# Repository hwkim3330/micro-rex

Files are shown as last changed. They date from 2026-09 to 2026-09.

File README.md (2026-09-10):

# MICRODUCK 원본으로 복귀

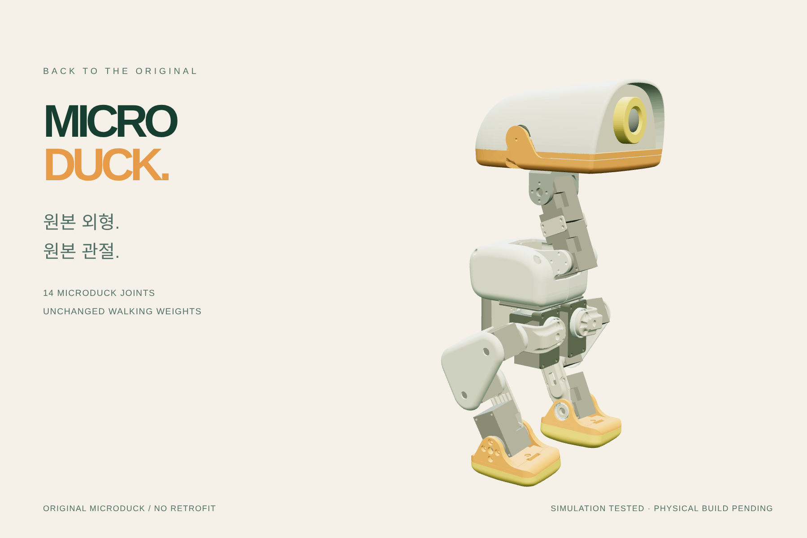
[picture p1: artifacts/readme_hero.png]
Microduck 원본 모델


현재 기본 화면은 **공룡 외장을 제거한 Microduck 원본**입니다. 원본 14개 관절과 공식 가중치의 계산 기록을 유지합니다. 이전 Micro Rex 외장은 비교 메뉴와 설계 기록으로 보존합니다.

원본 하드웨어의 비상업 조건은 그대로이며, 별도 상업용 독자 설계 [Micro X](https://github.com/hwkim3330/micro-x)의 권리 범위와 혼동하지 않습니다.

[원본 3D 보기](https://hwkim3330.github.io/micro-rex/web/) · [원본 외형 GLB](models/microduck_original.glb) · [원본 모델·자산](vendor/microduck/)

## 이전 Micro Rex 외장 기록

큰 눈, 작은 앞발, 긴 꼬리. **Microduck의 14개 관절과 공식 보행 가중치를 유지하는 작은 티렉스**를 만듭니다. 이 절은 이전 외장 설계 기록입니다.

[3D 모델 돌려보기](https://hwkim3330.github.io/micro-rex/) · [도면 PDF](drawings/Micro_Rex_Drawings.pdf) · [STEP 조립 파일](models/micro_rex_retrofit.step) · [GLB 전체 모델](models/micro_rex.glb) · [출력 STL](models/print/) · [검증 보고서](artifacts/validation.json)

현재 모델은 **Rev C 호환 외장 프로토타입**입니다. 눈의 뒤쪽 나사 고정, 머리 스트랩 슬롯, 안쪽 경량 포켓과 가장자리 보강부를 추가했습니다. 공식 가중치의 시뮬레이션, 무게중심 및 눈 고정부의 디지털 검사를 제공합니다. 실물 강도와 보행 시험은 아직 남아 있습니다.

먼저 **같은 관절의 Micro Rex**를 검증하고, 그다음 **저가형 Nano Rex**를 개발합니다. 네발형은 공개 모델에서 내렸습니다. [제품 순서와 완료 기준](docs/PRODUCT_SEQUENCE.md)

[가중치 시험](docs/POLICY_COMPATIBILITY.md) · [무게중심](artifacts/balance_study.json) · [눈 고정부](artifacts/retention_check.json)

## 무엇을 만들었나

- 카메라 앞을 개방한 둥근 볼판, 뒤쪽에서 나사로 고정하는 큰 눈, 위쪽 스트랩 브리지.
- 작은 앞발과 장착 브래킷, 속이 빈 분할 꼬리와 스트랩 장착판.
- 수정 가능한 CadQuery 원본, 개별 STEP/STL, 16개 부품의 출력 방향 정리본.
- 전체 로봇 GLB, 외장 STEP 조립 파일, MuJoCo 모델 및 지면이 포함된 장면.
- 실제 형상에서 생성한 17쪽 치수 참고 도면과 부품 목록.
- PC·모바일 브라우저에서 회전·확대·분해 보기 및 원본 부품 표시 전환.

기존 Microduck보다 개선하려는 항목은 외장 수정/교체의 용이성, 출력 파일·도면 제공, 추적 가능한 호환성 검사입니다. 속도·안정성·배터리 수명 향상은 아직 입증하지 않았습니다.

## 호환성 확인 범위

| 항목 | 결과 |
|---|---|
| 원본 정책 제어 관절 | **14개**, 이름·순서 유지 |
| 관절 축·위치·가동 범위 | 원본과 배열 비교 통과 |
| 액추에이터 연결·제어 범위·힘 제한 | 원본과 배열 비교 통과 |
| 센서 종류·차원·연결 ID | 원본과 배열 비교 통과 |
| 원본 모델 질량 | 737.24 g |
| Micro Rex 모델 질량 | 783.77 g, 추가 체결구 실측 전 |
| 예상 외장 추가 질량 | 46.53 g, PLA 실체적 환산 |
| 새 출력 STL | 16개, 폐곡면 및 양의 체적 검사 통과 |
| 단순 PD 자세 유지 | **원본과 Micro Rex 모두 3초 직립 실패**; 정책 평가가 아님 |
| 공식 ONNX + BAM 평지 시험 | 원본 12회 + 외장 12회, 각 10초 넘어짐 기준 미도달; 속도·방향 추종 부족 |
| 공식 서기 가중치 + 머리 명령 | 원본 3회 + 외장 3회, 각 10초 넘어짐 기준 미도달 |
| 같은 HOME 자세의 무게중심 변화 | 뒤로 0.96 mm / 위로 4.58 mm; 두 발 접지 가정의 정적 계산 |
| 눈·와셔 체결 공간 | 6개 STEP 조합 겹침 없음; 인발·토크 실물 시험 전 |
| 실물 조립 / sim-to-real | **미검증** |

원본 로봇의 입 모터는 14차원 보행 정책과 별도입니다. 이 패키지는 입 모터 제어를 추가하거나 15차원 정책으로 바꾸지 않습니다. 꼬리·앞발은 정적 외장입니다. 추가 질량과 관성은 모델에 반영했으며, 기존 보행 정책을 그대로 쓰면 동일 성능이 나온다고 보장하지 않습니다.

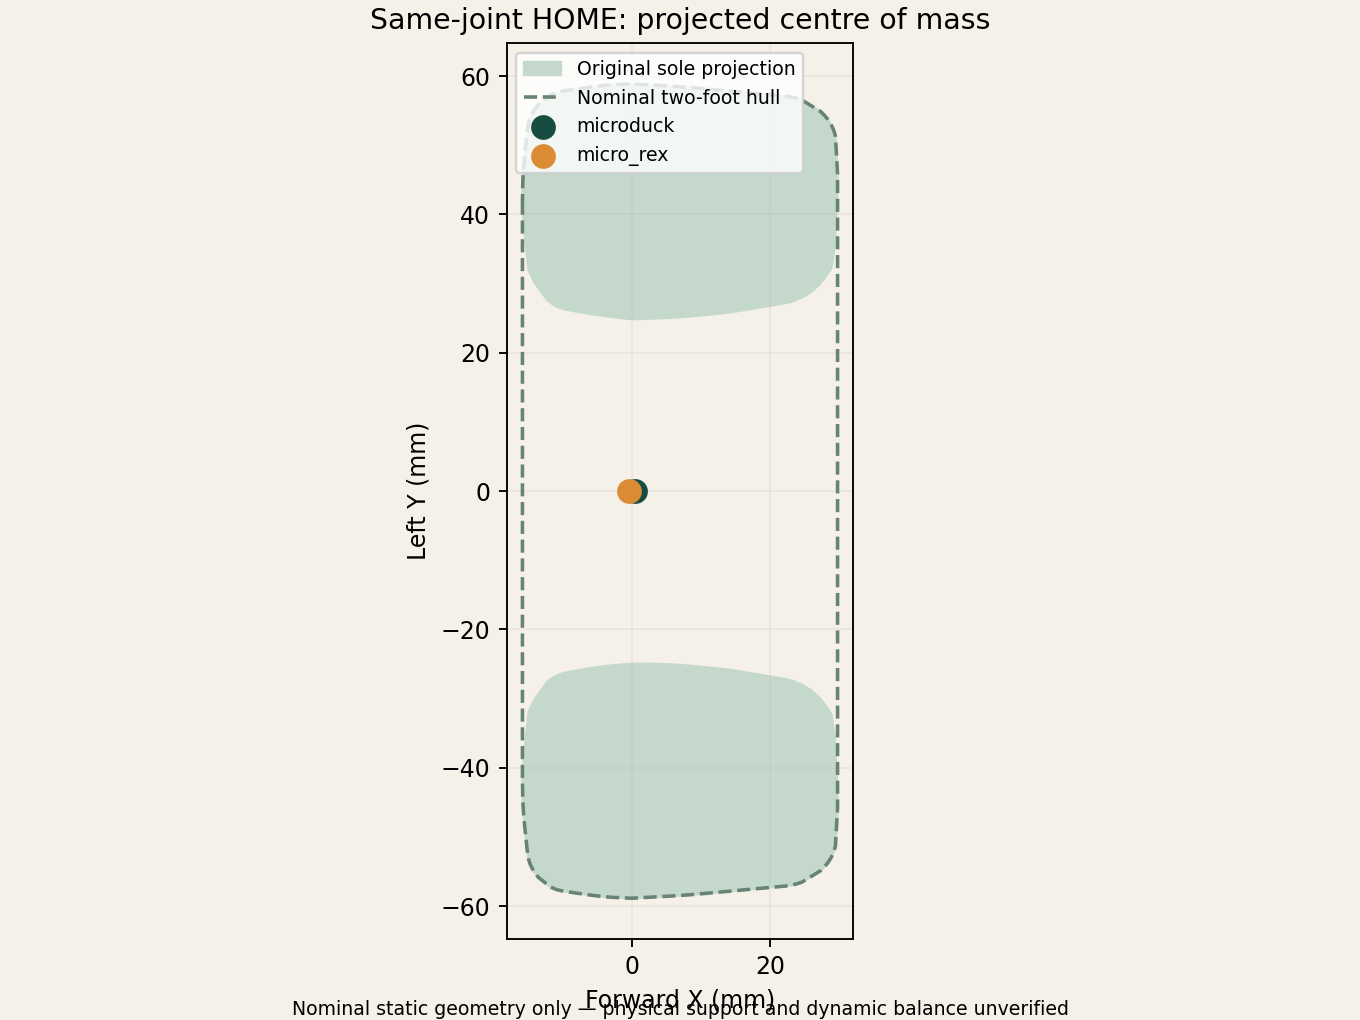
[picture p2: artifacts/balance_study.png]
원본과 Micro Rex의 정적 무게중심 투영 비교


목·머리 각도를 바꾼 일곱 자세에서 가정한 두 발 지지영역까지 최소 여유는 7.46 mm입니다. 실제 접촉력이나 보행 중 안정성을 증명하는 값은 아닙니다. 머리 5g·몸통 5g의 미실측 체결구 예산도 별도 민감도 계산에 기록했습니다.

## 원본 자료도 함께 받기

공식 제어 소프트웨어, 공식 RL/메시, 공식 Robot HAT 회로도, 커뮤니티 역설계 도면을 서로 구분해 고정 커밋으로 연결합니다.

```bash
git clone --recurse-submodules https://github.com/hwkim3330/micro-rex.git
cd micro-rex
```

이미 클론했다면 `git submodule update --init --recursive`를 실행합니다. 모든 출처와 커밋은 [upstream.lock.json](upstream.lock.json), 자료별 상태는 [출처 기록](docs/SOURCES.md)에 있습니다. 커뮤니티 역설계 자료는 공식 공장 도면으로 취급하지 않습니다.

## 모델 재생성

Python 3.11 이상, Linux 기준입니다.

```bash
python -m venv .venv
source .venv/bin/activate
pip install -r requirements.txt
python cad/build.py
python tools/print_parts.py
python tools/tail_continuous.py
python tools/retention_check.py
python tools/balance_study.py
python tools/validate.py
MUJOCO_GL=egl python tools/render.py  # EGL 환경 필요; 정적 렌더는 이미 포함
python tools/drawings.py
```

기구를 변경한 뒤에는 [정책 평가](docs/POLICY_COMPATIBILITY.md)를 다시 실행해야 기존 평가 기록의 모델 SHA가 맞습니다. README 대표 이미지는 `node tools/readme-portrait.mjs`로 현재 GLB와 기록 자세에서 다시 생성합니다.

`models/parts/`는 조립 기준 좌표, `models/print/`는 중심 정렬 및 출력면을 맞춘 파일입니다. 원본 로봇의 STL은 `vendor/microduck/assets/`에 있습니다. 전체 조립 STEP은 **새 외장**만 정확한 CAD 솔리드로 담고, 원본 전체 로봇 형상은 GLB와 upstream STL/MJCF로 제공합니다.

```bash
python -m http.server 5190
# http://127.0.0.1:5190/web/
```

뷰어 라이브러리도 저장소 안에 있으므로 외부 CDN이 필요 없습니다. 모델을 MuJoCo에서 열려면 `models/scene.xml`을 사용합니다.

개발자 브라우저 검사: `npm ci --ignore-scripts && npm run test:viewer`. 설치된 Chrome 경로는 `CHROME_PATH`로 지정할 수 있습니다.

## 제작 전 확인

[조립 및 검증 항목](docs/ASSEMBLY.md)을 먼저 확인하세요. 현재 꼬리 조인트, 스트랩 고정, 나사 체결 길이와 가동 중 간섭은 실물 확인 대상입니다. 도면은 프로토타입 치수 참고용이며 공장 제작 승인도면이 아닙니다.

## 라이선스

독립 프로젝트이며 Pollen Robotics 또는 Hugging Face의 공식 제품이 아닙니다.

- 새 코드: Apache-2.0.
- 원본 하드웨어 모델: upstream의 **CC BY-SA-NC** 표기 유지.
- 새 외장 및 파생 모델·도면: **CC BY-NC-SA 4.0**, 원본 하드웨어 조건도 적용.
- Three.js: MIT.

[자세한 출처·라이선스](licenses/HARDWARE.md). 상업 사용을 허용하는 하드웨어 패키지가 아닙니다.

### 공개 웹 제작실

[GitHub Pages](https://hwkim3330.github.io/micro-rex/)에서 14개 관절 자세 조절, 부품 선택 및 치수 확인, 조립·분해 보기, 원본 부품 표시 전환, 카메라 방향 선택과 PNG 저장을 제공합니다. 부품 표에서 출력용 mm STL과 STEP을 내려받을 수 있습니다. PC와 모바일 레이아웃을 제공합니다.

브라우저 수동 관절 조절은 원본 MJCF에서 생성한 **기구학 시연**입니다. 새로 추가한 **시뮬레이션 기록 재생**은 공식 ONNX 가중치로 계산한 원본·외장 모델의 몸체와 관절 좌표를 재생합니다. 실물 제작과 보행 검증 완료를 의미하지 않습니다.

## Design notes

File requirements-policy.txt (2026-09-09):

# Separate policy environment; CAD generation uses requirements.txt / MuJoCo 3.4.
mujoco==3.10.0
numpy>=2,<3
onnxruntime==1.24.1
better-actuator-models @ git+https://github.com/Rhoban/bam.git@62bd8ce12154340be97e06f7f41a0ca8f116d967

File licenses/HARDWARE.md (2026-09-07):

# Hardware, geometry and attribution

Original Microduck model and meshes: **Pollen Robotics**.
Source: https://github.com/pollen-robotics/microduck_rl
The exact source commit is recorded in `upstream.lock.json`.

The upstream README states: “Hardware design files are licensed under Creative Commons BY-SA-NC.”
It does not specify a version in that notice. The unmodified model files and STL meshes in
`vendor/microduck/` retain those upstream terms; this repository does not relicense them as Apache.
`vendor/microduck/UPSTREAM_README.md` preserves the original notice.

New Micro Rex CAD geometry, derivative assembly meshes, model XML, drawings and renderings:
Copyright 2026 hwkim3330, **CC BY-NC-SA 4.0**, subject also to the original upstream hardware terms.
Attribution: “Micro Rex by hwkim3330, based on Microduck by Pollen Robotics.”
Changes: T-rex cheek shells, decorative teeth/brows, bridges, forelimbs, brackets and tail;
additive inertial properties; assembled reference models and derived drawings.
Non-commercial use only; preserve attribution and ShareAlike when redistributing derivatives.

New build/validation/viewer software is Apache-2.0, except Three.js vendored files,
which retain their included MIT license in `web/vendor/three/LICENSE`.

The community `microduck-replica` and official electronics repositories are linked/pinned as
upstream submodules; their respective licenses remain authoritative. Community reconstructions
are not factory drawings, and are not described as physically verified Micro Rex hardware.

License text for new Micro Rex design work:
https://creativecommons.org/licenses/by-nc-sa/4.0/legalcode.en

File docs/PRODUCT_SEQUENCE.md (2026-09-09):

# Micro Rex first, Nano Rex next

## 1. Micro Rex — same joints

Keep Microduck's 14 policy joints, XL330 actuator class, joint geometry, sensors and 61→14 policy interface. Improve the dinosaur shell, retention, maintenance and presentation. Re-run the unchanged official checkpoint whenever added geometry changes mass, inertia or contacts.

Current Rev C changes: continuous rounded cheeks, larger visible eye whites, M2 rear eye retention, strap slots in both head bridges, rounded forearm corners, and a README portrait rendered from the actual CAD.

Physical acceptance remains open: eye pull/torque tests, shell retention under vibration, cable and camera clearances, repeated head/joint motion, tail mounting, drop testing, thermal tests and actual gait trials. Do not describe an untested shell as tougher than Microduck. Start with coupons and one assembled head before ordering a batch.

## 2. Nano Rex — lower cost

Deferred until the same-joint Micro Rex is validated. Compare actuator, battery, electronics and assembly costs using supplier quotations and loaded-joint measurements. Price and BOM are not fixed yet.

Changing actuator torque, link lengths, joint count or mass distribution invalidates any assumption that the Microduck checkpoint will transfer unchanged. Nano Rex must have its own transfer evaluation and may require retraining. No Nano Rex manufacturing files or claimed price are released yet.

Q4 is retired from the public Micro X viewer; its previous CAD is retained as historical work.

The source hardware's noncommercial terms remain separate from the Apache-2.0 policy weights. Commercial hardware rights need to be resolved before selling a derivative robot.

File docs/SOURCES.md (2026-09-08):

# Sources and scope

Four public repositories were cloned for this work. Exact commits are pinned in `upstream.lock.json` and `.gitmodules` / gitlinks.

| Source | Role | What is and is not established |
|---|---|---|
| [pollen-robotics/microduck](https://github.com/pollen-robotics/microduck) | Official Rust control runtime | Runtime source, configuration and control contract; not a Micro Rex firmware validation |
| [pollen-robotics/microduck_rl](https://github.com/pollen-robotics/microduck_rl) | Official training source, MJCF and STL | Actual reference model used here. `robot_walk.xml` has 14 policy actuators; the runtime's mouth channel is separate |
| [pollen-robotics/elec_RPI_Robot_HAT](https://github.com/pollen-robotics/elec_RPI_Robot_HAT) | Official KiCad electronics | Includes schematic, PCB, production outputs and BOM. Presence of this board does not establish a complete factory robot build package |
| [fanhao375/microduck-replica](https://github.com/fanhao375/microduck-replica) | Community reconstruction | Assembly drawings, inferred mechanical/electronic details; treated as third-party reconstruction, not authoritative factory drawings |

The upstream MJCF links an Onshape document. We preserve the link inside the original XML but do not claim to have retrieved editable original Onshape parts.

The new CAD generator, drawings, build files and viewer are original work in this repository. The complete robot render/GLB and MuJoCo derivative use the official Microduck meshes and preserve their attribution and hardware licensing. No community CAD is silently represented as an original manufacturer file.

`vendor/microduck/` is a ready-to-use snapshot of the official model files and meshes. Full upstream software and hardware repositories are pinned submodules under `upstream/`; retrieve them using `git clone --recurse-submodules`.

The static renders show the reference assembly pose. They are computer-generated views of the delivered model, not photographs of a built Micro Rex.

## Interactive design references

The following user-supplied Spaces were inspected as interaction references. Their application code and additional assets were not copied into this site:

- [Microduck simulator](https://huggingface.co/spaces/pollen-robotics/microduck-simulator), revision `e81974b932c7ca1819843b7bb3dcd42e2993e98e`: simulator presentation and controls.
- [Microduck anatomy](https://huggingface.co/spaces/mishig/microduck-anatomy), revision `5329ff5db7c6baa5c15def88085f842e0221395e`: inspectable anatomy and articulated model interaction.
- [Reachy Mini 3D voice](https://huggingface.co/spaces/pollen-robotics/reachy-mini-3d-voice), revision `bdcac3f73e9b7def1a71ee03d2ca7a858fd0004b`: character and robot presentation.

Our browser rig is independently exported from the vendored upstream MJCF using `tools/export_rig.py`. It preserves body hierarchy, local joint axes, pivots and ranges. It is a kinematic viewer, without collision enforcement, balance control or a voice backend. Moving a slider is not evidence of feasible hardware motion.

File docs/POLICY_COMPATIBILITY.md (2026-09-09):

# Microduck weights compatibility / Rev C

사용자 요청에 따라 Microduck 원본 기구를 유지하는 Micro Rex 호환 개발을 재개했습니다. 판매용 독립 기구 Micro X와 달리, 이 저장소는 원본 하드웨어의 비상업 조건을 유지합니다.

## 실제로 사용한 자료

- 원본 모델과 추론 코드: `upstream.lock.json`의 Microduck RL 커밋. 관절 14개와 관절·몸체 배치, 센서 순서를 유지합니다.
- [공식 정책 저장소](https://huggingface.co/pollen-robotics/microduck-policies/tree/088524a64e2557dc453256b6071dbb9d23888802): `alpha_walking.onnx`를 변경하거나 재학습하지 않았습니다. 다운로드 URL과 SHA256은 `artifacts/policy_source.json`에 고정합니다. 모델 카드의 가중치 라이선스는 Apache-2.0입니다. 이는 하드웨어의 상업 이용 허가가 아닙니다.
- 관측 61개, 행동 14개, 50 Hz. upstream 추론 코드의 HOME 기준 자세, 투영 중력, 관절 상대 위치·속도, 이전 행동과 명령 배열을 사용합니다.
- BAM M6 XL330 모터 모델, 7.4 V, firmware kp 200, 전압 강하 gain 0.1. MuJoCo는 원본 추론 코드가 사용하는 3.10.0을 별도 환경에 설치했습니다. CAD 검사 환경은 3.4.0입니다.

## 비교 결과

평평한 바닥에서 정지, 0.1 m/s 전진, 0.3 m/s 전진, 0.3 rad/s 회전 명령 각각 초기 관절 잡음 seed 3개를 사용해 10초씩 평가했습니다. 원본 12회와 외장 포함 12회에서 정한 넘어짐 기준(몸통 기울기 45° 초과 또는 높이 65 mm 미만)에 도달하지 않았습니다.

외장 모델의 0.3 m/s 명령 시험에서 X 이동은 1.009–1.064 m, Y 이동은 −0.340–−0.202 m였습니다. 속도 및 직진 추종이 명령과 일치하지 않습니다. 0.1 m/s 명령에서는 거의 전진하지 않았고 회전 명령 추종도 작았습니다. 원본에서도 같은 종류의 문제가 나타났습니다. **가중치 로딩·추론·짧은 평지 동작을 확인했지만, 모든 기능의 호환이나 실물 보행을 검증한 것은 아닙니다.**

외장은 46.53 g의 추정 질량과 관성을 더합니다. 추가 나사·와셔·스트랩의 실측 질량은 포함 전입니다. 외장 충돌은 보수적 단순 형상으로 근사하며 실물 간섭이나 강도 검증을 대체하지 않습니다. 상세 수치는 `artifacts/policy_evaluation.json`을 따릅니다.

별도로 공식 `alpha_stand.onnx`를 그대로 사용해 머리 pitch 명령 −0.25/0/+0.25 rad, seed 0으로 두 모델을 각 3회 시험했습니다. 10초 동안 넘어짐 기준에는 도달하지 않았습니다. 이 시험도 명령 추종 정확도나 장기 신뢰성의 합격 판정은 아닙니다.

## 재현

```sh
git submodule update --init upstream/microduck_rl
python3 -m venv .venv-policy
.venv-policy/bin/python -m pip install -r requirements-policy.txt
.venv-policy/bin/python tools/fetch_policy.py
.venv-policy/bin/python tools/evaluate_policy.py
```

가중치는 `.cache/policies`에 저장하며 이 저장소에서 다시 배포하지 않습니다. 다운로드는 고정 리비전을 사용하고 평가 전에 SHA256을 대조합니다. walking 비교 24회와 standing/head 비교 6회를 수행합니다. 가상 환경과 모델 가중치는 git에서 제외합니다.

웹의 기록 재생은 이 평가에서 저장한 실제 관절·몸체 좌표를 사용합니다. ONNX를 브라우저에서 실행하거나 실제 로봇을 연결하는 기능은 아닙니다. 현재 기록은 전진 0.3 m/s, seed 0 시험입니다.

## 외장 변경

원본 머리와 다리 구조를 유지하고 옆 볼을 곡선으로 다듬고 주둥이 길이를 줄였습니다. 기존 `brow_*` 부품 ID는 큰 볼록 눈 부품으로 변경했습니다. 눈동자는 도색 의도이며 MuJoCo의 검은 표시는 시각 근사입니다. 실제 눈 부품 고정, 커버와 원본 하우징 간 공차 및 카메라 시야 확인은 남아 있습니다.

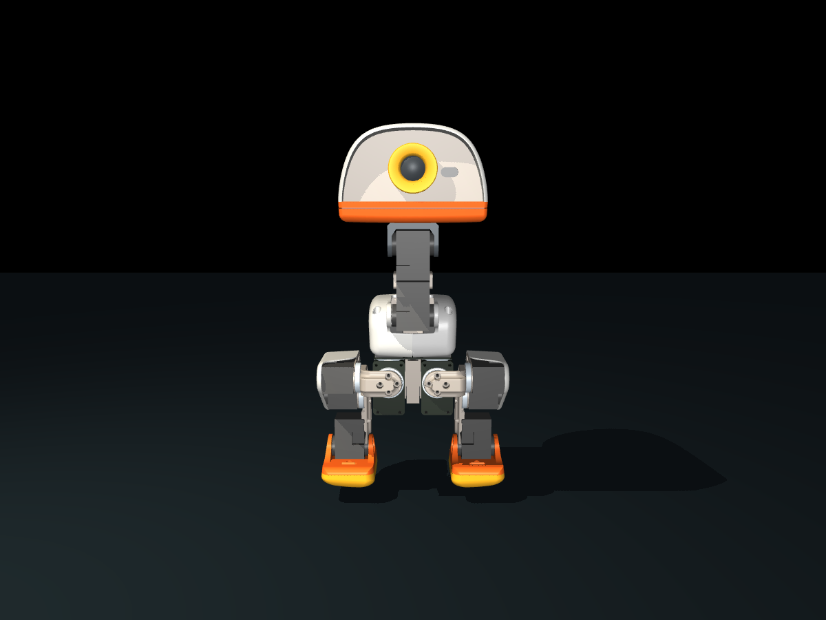
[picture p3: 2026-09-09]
artifacts/microduck_reference_front.png

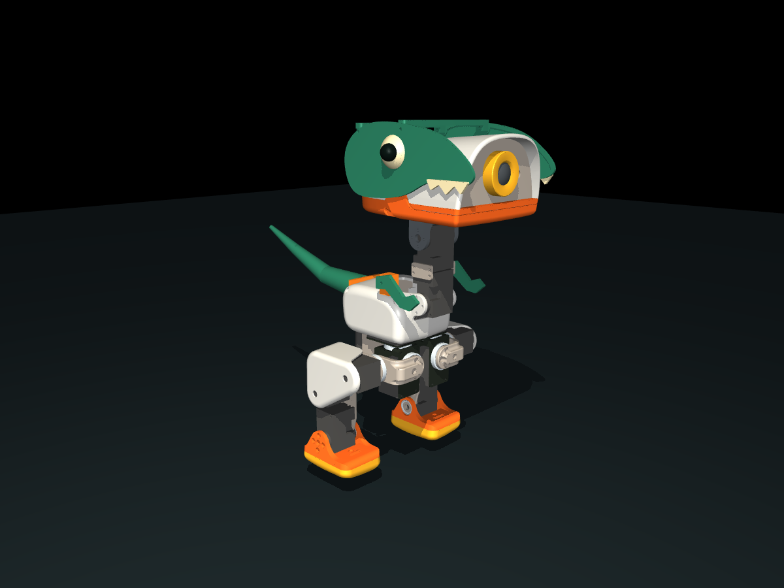
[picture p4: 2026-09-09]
artifacts/micro_rex_hero.png

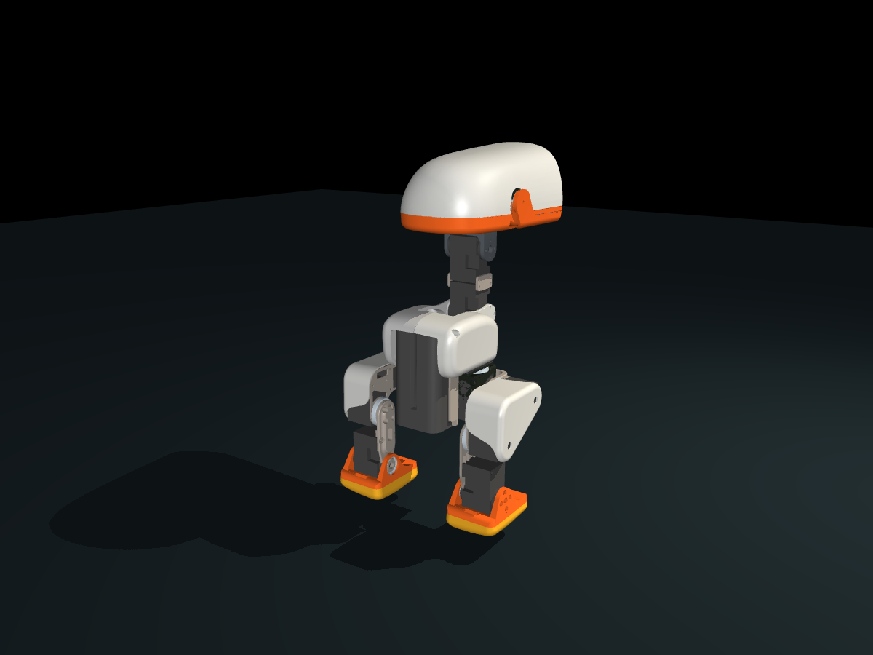
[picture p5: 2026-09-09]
artifacts/microduck_reference_rear.png

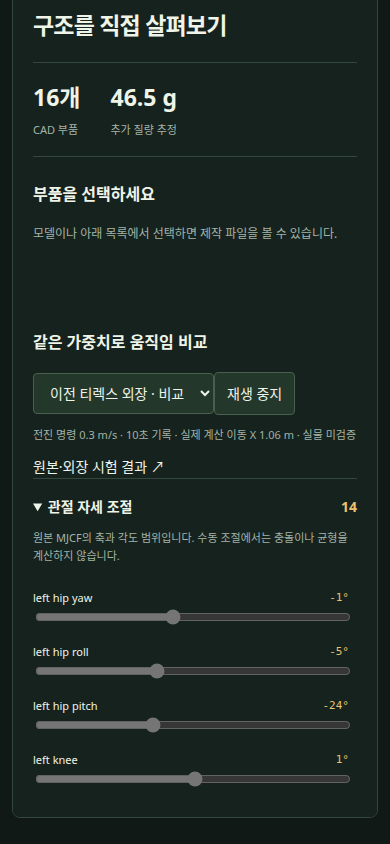
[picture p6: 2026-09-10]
artifacts/policy_mobile.png

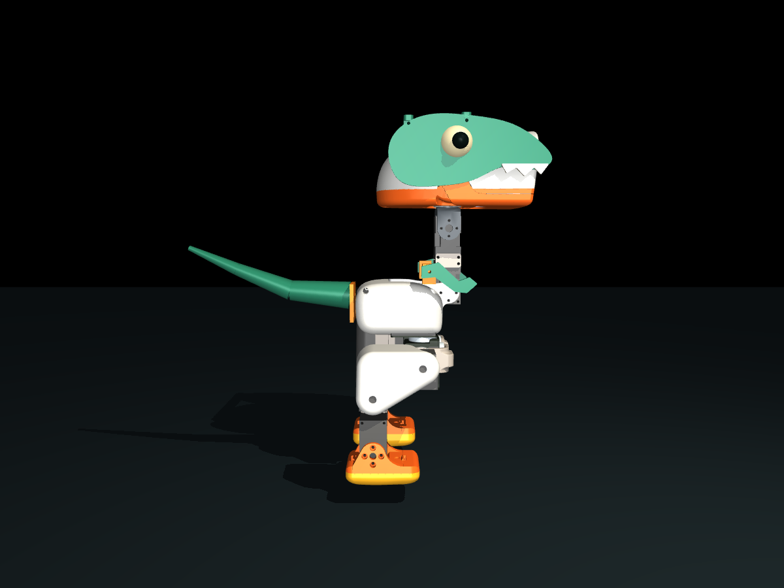
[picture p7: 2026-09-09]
artifacts/micro_rex_side.png

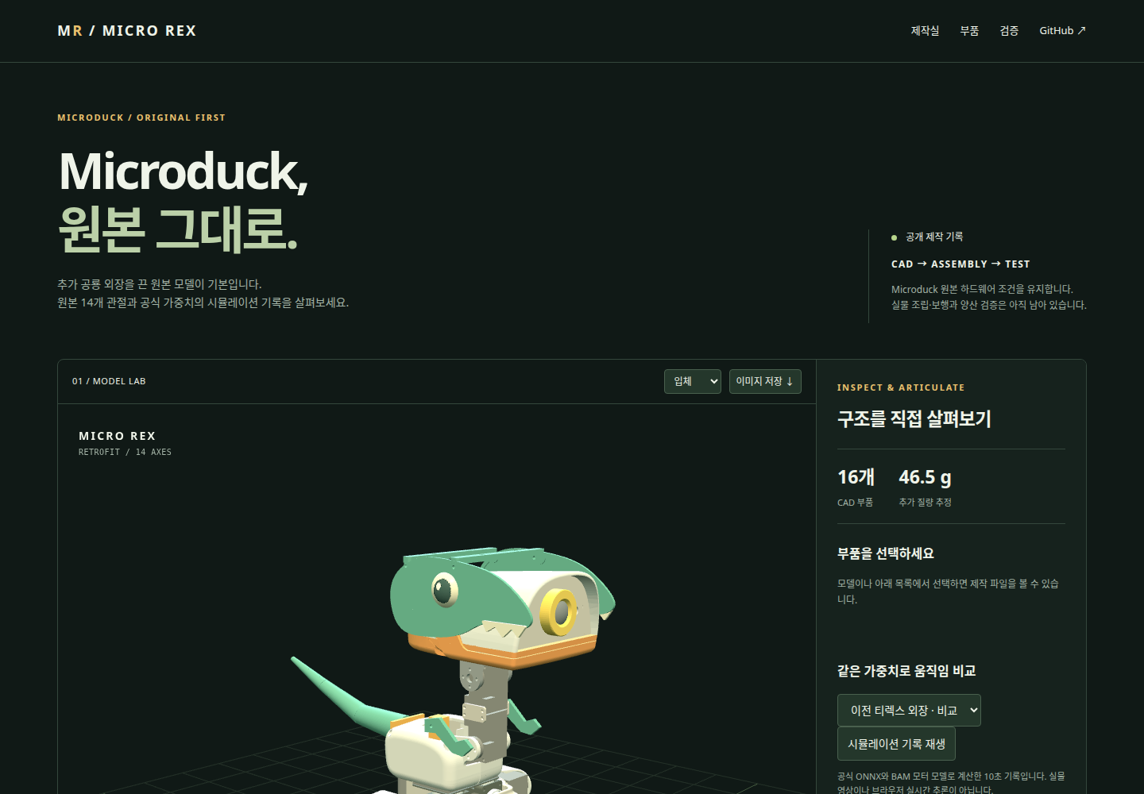
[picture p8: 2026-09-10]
artifacts/viewer_desktop.png

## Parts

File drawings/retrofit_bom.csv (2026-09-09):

part | qty | material_estimate | mass_g | STL | STEP
skull_cheek_left | 1 | PLA estimate, density 1.24 g/cm3 | 7.688 | models/parts/skull_cheek_left.stl | models/step/skull_cheek_left.step
teeth_left | 1 | PLA estimate, density 1.24 g/cm3 | 0.44 | models/parts/teeth_left.stl | models/step/teeth_left.step
brow_left | 1 | PLA estimate, density 1.24 g/cm3 | 1.917 | models/parts/brow_left.stl | models/step/brow_left.step
skull_cheek_right | 1 | PLA estimate, density 1.24 g/cm3 | 7.688 | models/parts/skull_cheek_right.stl | models/step/skull_cheek_right.step
teeth_right | 1 | PLA estimate, density 1.24 g/cm3 | 0.44 | models/parts/teeth_right.stl | models/step/teeth_right.step
brow_right | 1 | PLA estimate, density 1.24 g/cm3 | 1.917 | models/parts/brow_right.stl | models/step/brow_right.step
head_bridge_1 | 1 | PLA estimate, density 1.24 g/cm3 | 3.447 | models/parts/head_bridge_1.stl | models/step/head_bridge_1.step
head_bridge_2 | 1 | PLA estimate, density 1.24 g/cm3 | 3.447 | models/parts/head_bridge_2.stl | models/step/head_bridge_2.step
tail_segment_1 | 1 | PLA estimate, density 1.24 g/cm3 | 5.107 | models/parts/tail_segment_1.stl | models/step/tail_segment_1.step
tail_segment_2 | 1 | PLA estimate, density 1.24 g/cm3 | 3.28 | models/parts/tail_segment_2.stl | models/step/tail_segment_2.step
tail_segment_3 | 1 | PLA estimate, density 1.24 g/cm3 | 1.376 | models/parts/tail_segment_3.stl | models/step/tail_segment_3.step
tail_saddle | 1 | PLA estimate, density 1.24 g/cm3 | 3.415 | models/parts/tail_saddle.stl | models/step/tail_saddle.step
forearm_left | 1 | PLA estimate, density 1.24 g/cm3 | 1.527 | models/parts/forearm_left.stl | models/step/forearm_left.step
arm_standoff_left | 1 | PLA estimate, density 1.24 g/cm3 | 1.655 | models/parts/arm_standoff_left.stl | models/step/arm_standoff_left.step
forearm_right | 1 | PLA estimate, density 1.24 g/cm3 | 1.527 | models/parts/forearm_right.stl | models/step/forearm_right.step
arm_standoff_right | 1 | PLA estimate, density 1.24 g/cm3 | 1.655 | models/parts/arm_standoff_right.stl | models/step/arm_standoff_right.step
eye_retention_screw | 2 | Candidate M2 x 6 plastic thread-forming; supplier/torque pending
eye_retention_washer | 2 | Candidate OD8 ID2.2 thickness0.5 mm; physical fit pending
head_retention_strap | 2 | Candidate for 4 x 2 mm slots; routing/strength pending

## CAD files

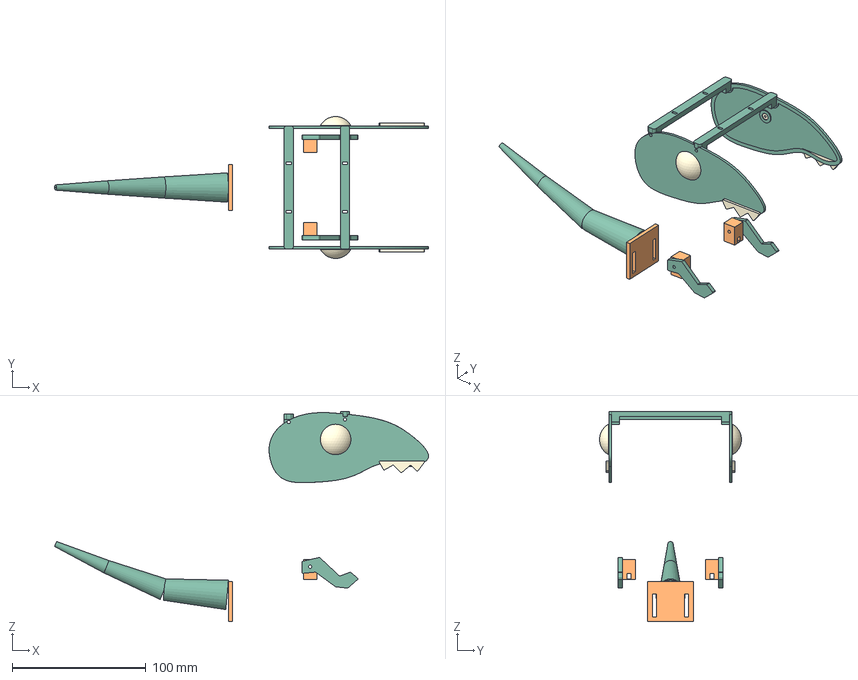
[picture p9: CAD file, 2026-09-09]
models/micro_rex_retrofit.step
279.1 x 105.9 x 157.0 mm
skull_cheek_left
teeth_left
brow_left
skull_cheek_right
teeth_right
brow_right
head_bridge_1
head_bridge_2
tail_segment_1
tail_segment_2
tail_segment_3
tail_saddle
forearm_left
arm_standoff_left
forearm_right
arm_standoff_right

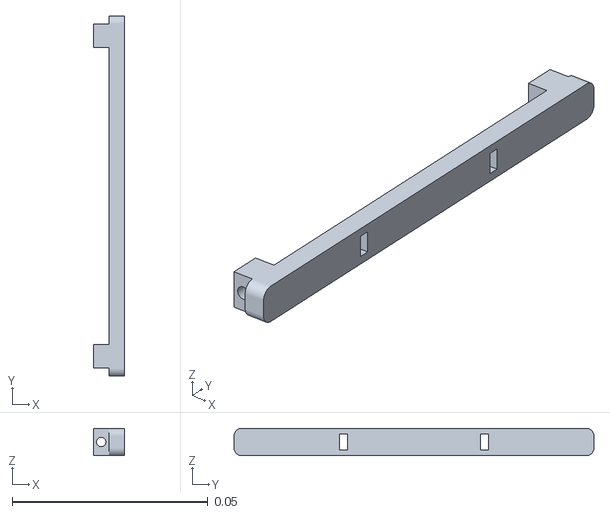
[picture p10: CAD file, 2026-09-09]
models/parts/head_bridge_2_local.stl
0.008 x 0.092 x 0.007

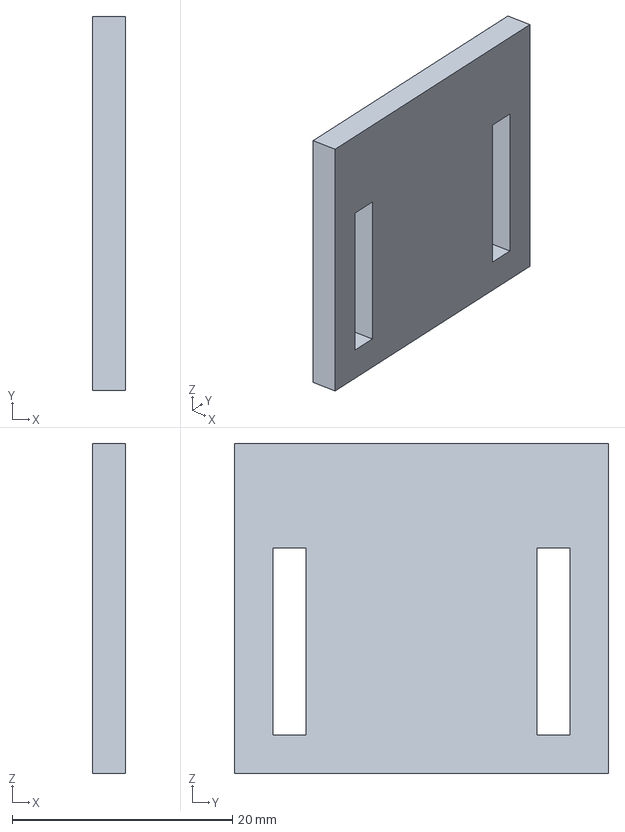
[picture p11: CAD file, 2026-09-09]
models/step/tail_saddle.step
3.00 x 34.0 x 30.0 mm

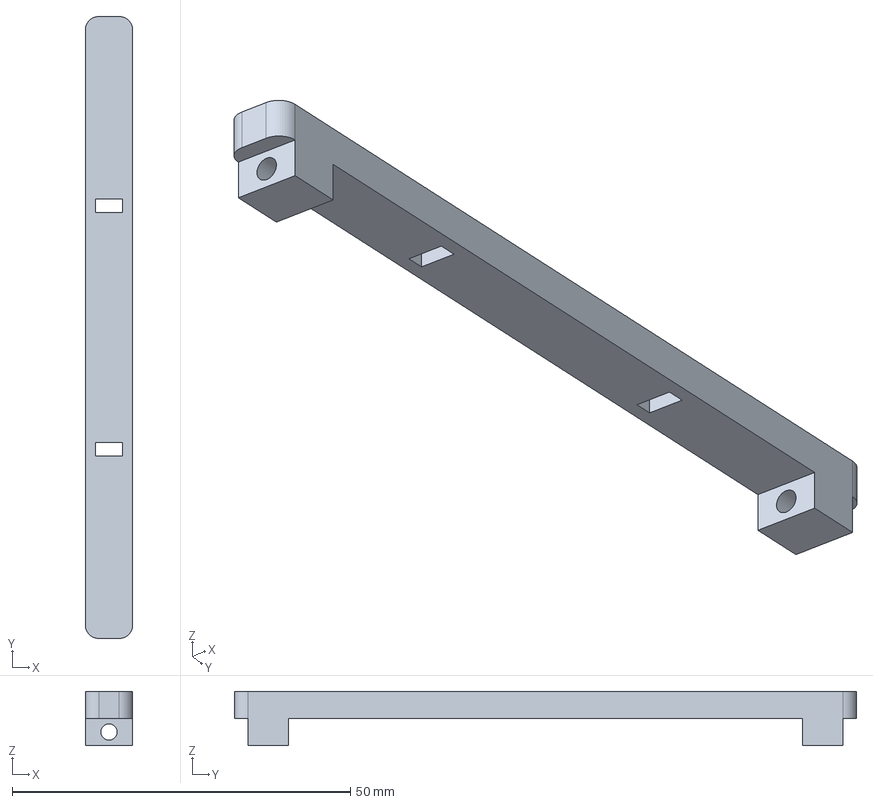
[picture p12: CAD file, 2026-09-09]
models/step/head_bridge_2.step
7.00 x 92.0 x 8.00 mm

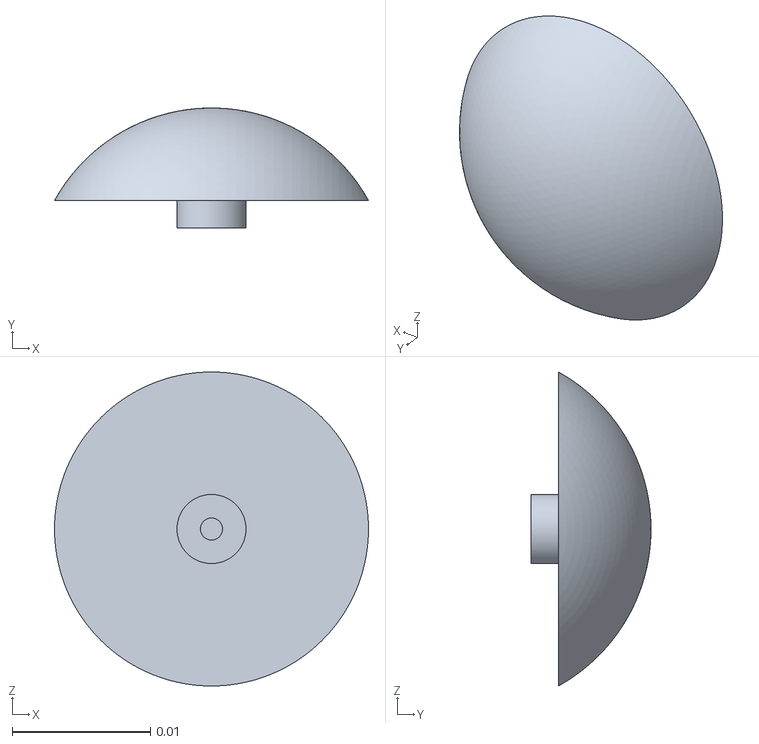
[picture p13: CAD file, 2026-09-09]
models/parts/brow_left_local.stl
0.0227 x 0.0087 x 0.0227

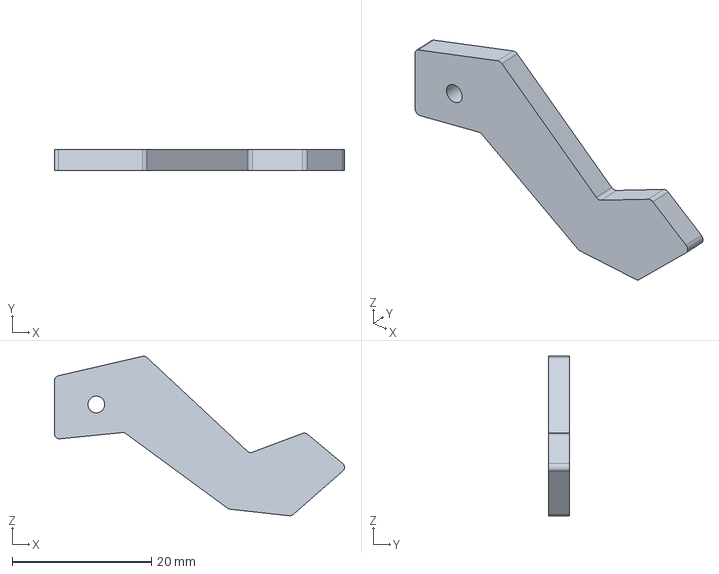
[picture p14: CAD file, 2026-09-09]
models/step/forearm_right.step
41.6 x 3.00 x 22.9 mm

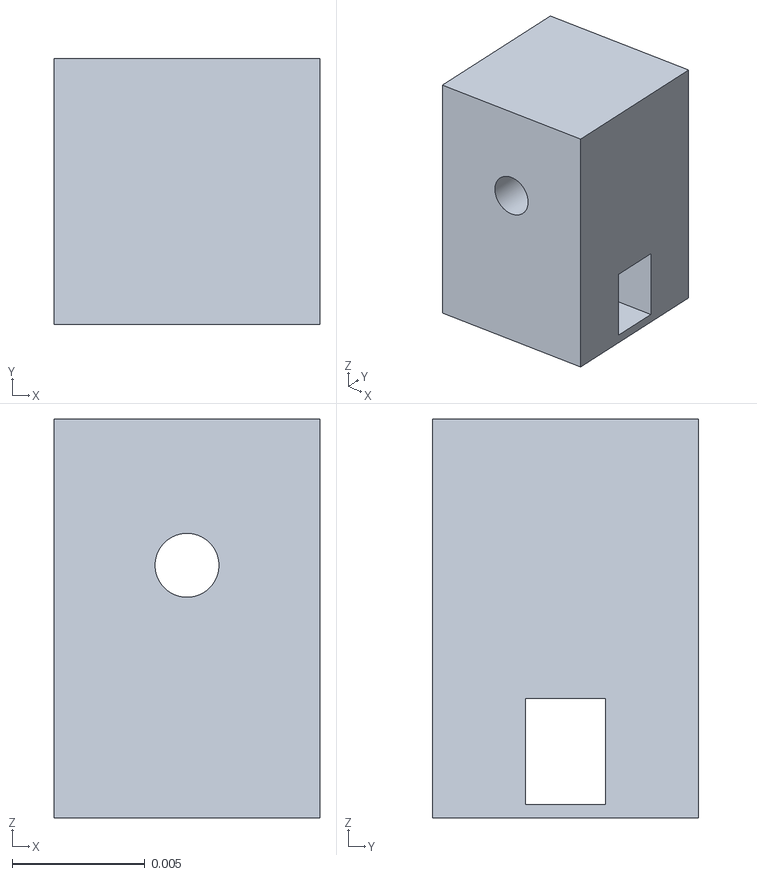
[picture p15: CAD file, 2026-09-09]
models/parts/arm_standoff_left_local.stl
0.01 x 0.01 x 0.015

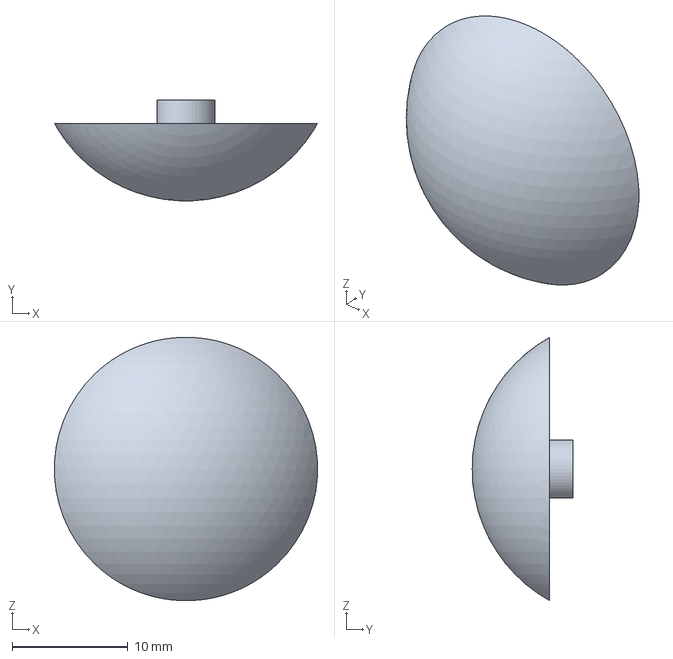
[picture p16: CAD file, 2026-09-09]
models/step/brow_right.step
22.7 x 8.68 x 22.7 mm

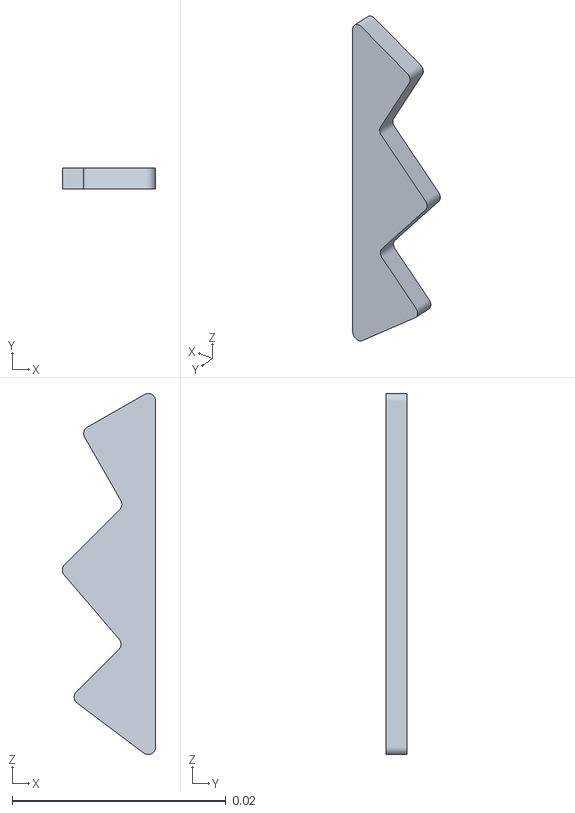
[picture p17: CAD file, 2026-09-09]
models/parts/teeth_right_local.stl
0.00875 x 0.002 x 0.0338

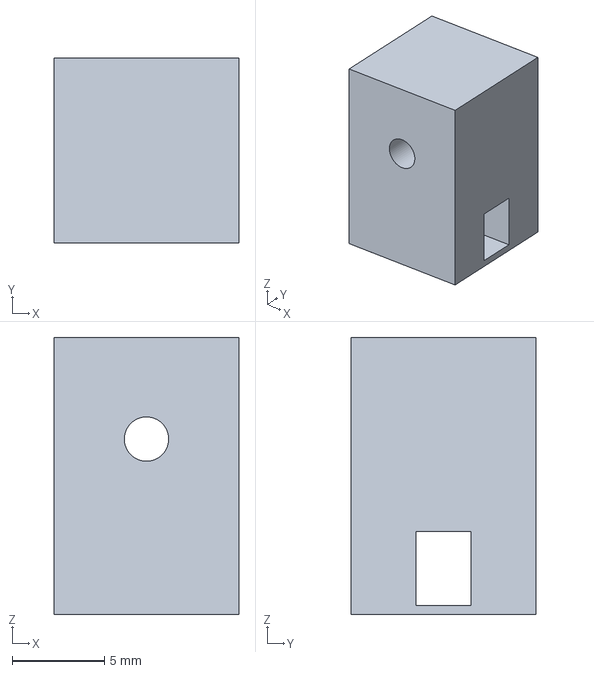
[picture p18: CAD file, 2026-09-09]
models/step/arm_standoff_right.step
10.0 x 10.0 x 15.0 mm

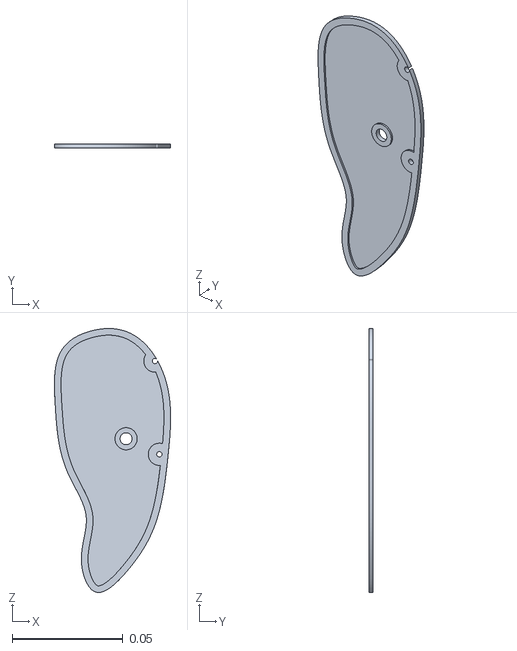
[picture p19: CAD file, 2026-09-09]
models/parts/skull_cheek_left_local.stl
0.0524 x 0.002 x 0.119

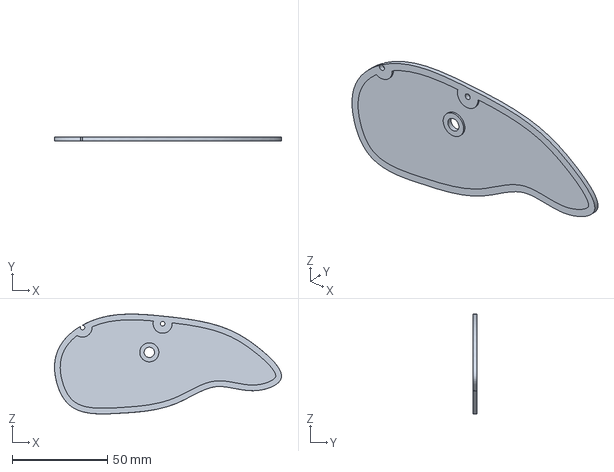
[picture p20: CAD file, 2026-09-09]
models/step/skull_cheek_left.step
119.0 x 2.00 x 52.4 mm

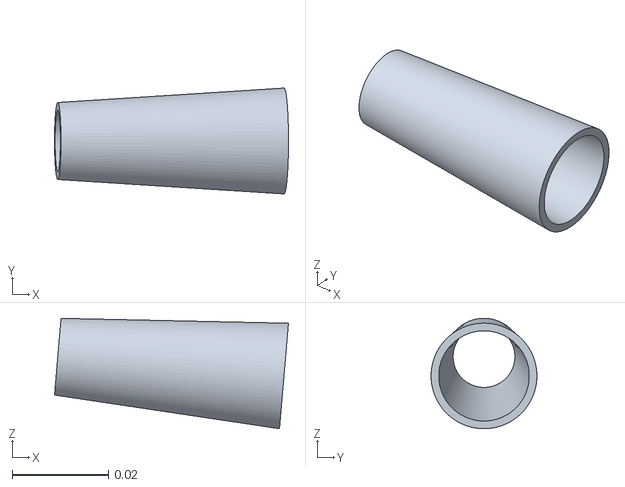
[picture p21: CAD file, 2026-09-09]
models/parts/tail_segment_1_local.stl
0.0486 x 0.022 x 0.0229

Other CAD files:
models/parts/head_bridge_1_local.stl
models/parts/teeth_left_local.stl
models/step/brow_left.step
models/step/forearm_left.step
models/parts/skull_cheek_right_local.stl
models/parts/arm_standoff_left.stl
models/parts/arm_standoff_right.stl
models/parts/arm_standoff_right_local.stl
models/parts/brow_left.stl
models/parts/brow_right.stl
models/parts/brow_right_local.stl
models/parts/forearm_left.stl
models/parts/forearm_left_local.stl
models/parts/forearm_right.stl
models/parts/forearm_right_local.stl
models/parts/head_bridge_1.stl
models/parts/head_bridge_2.stl
models/parts/skull_cheek_left.stl
models/parts/skull_cheek_right.stl
models/parts/tail_continuous.stl
models/parts/tail_saddle.stl
models/parts/tail_saddle_local.stl
models/parts/tail_segment_1.stl
models/parts/tail_segment_2.stl
models/parts/tail_segment_2_local.stl
models/parts/tail_segment_3.stl
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

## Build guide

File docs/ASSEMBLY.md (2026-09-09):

# Rev C 조립 참고

이 문서는 디지털 설계의 조립 의도를 설명한다. 실물 시험과 공차 보정이 아직 필요하다.

## 보존하는 원본

다리 링크·발바닥·모터·목·카메라·머리 전자부품은 원본 그대로 둔다. 임의의 원본 나사 위치를 추정해서 새 외장에 복제하지 않았다. 머리 외장은 자체 브리지와 M2 체결구, 몸통 부품은 스트랩 장착을 시험하는 구조다.

## 새 부품

1. **두개골 외장**: 좌우 `skull_cheek_*`와 `head_bridge_1/2`. 좌우 안쪽 면은 Y=±44 mm, 브리지 보스가 이 면에 닿는다. 조립 기준은 원본 MJCF의 영점 자세이며 단위는 mm.
2. **눈·이빨**: 기존 `brow_*` ID는 볼록 눈 부품이다. 눈의 Ø5 mm 스템을 볼판 Ø5.4 mm 구멍에 넣고 뒤쪽에서 M2×6 플라스틱용 나사와 외경 8 mm·두께 0.5 mm 와셔로 고정하는 잠정안이다. 눈의 Ø1.6×6 mm 파일럿에 예상 5.2 mm 체결된다. 체결 토크와 인발력은 실물 시험 전이다. 이빨 고정은 아직 검증 전이며 실제 물기용이 아니다.
3. **앞발**: `forearm_*`와 `arm_standoff_*`의 지름 2.4 mm 구멍을 맞춘다. 브래킷 스트랩 채널은 3×4 mm. 실제 케이스와의 맞물림은 확인 전이다.
4. **꼬리**: `tail_segment_1/2/3`와 `tail_saddle`. 장착판 슬롯은 3×17 mm. 분할 꼬리는 접합/접착 길이 확인이 필요하다. 테스트용 일체형 파일도 `models/print/tail_continuous.stl`에 제공한다.
5. **체결구 후보**: 머리용 M2×12 4개, 앞발용 M2×16 2개, M2 너트 6개, 눈용 M2×6 플라스틱용 나사 2개와 와셔 2개. 체결 길이와 공구 접근성은 실물에서 확인한다. 각 머리 브리지의 4×2 mm 슬롯 쌍에 스트랩을 통과시켜 원본 하우징에 고정하는 경로를 시험한다. 슬롯 추가가 배선·통풍·카메라를 피하는 경로 검증을 뜻하지는 않는다. 몸통의 3 mm 슬롯은 그보다 좁은 스트랩을 사용한다.

## 출력 파일

- `models/print`: 출력면이 Z=0, XY 중심이 원점. 기본 STL 단위는 mm.
- `models/parts`: 조립 참조 좌표. 이 파일을 일괄 불러오면 외장 조립 위치를 유지한다.
- `models/step`: 동일 부품의 편집 가능한 CAD 솔리드.
- `models/micro_rex.glb`: 원본 메커니즘과 새 외장을 포함한 전체 시각 모델. 단위 m.
- `models/micro_rex_retrofit.step`: 새 외장의 CAD 조립. 원본 STL을 가짜 편집형 솔리드로 변환하지 않았다.

처음부터 전체를 출력하기보다 구멍/슬롯과 브리지 한 세트를 먼저 확인한다. 프린터별 수축과 구멍 오차를 실제 시편으로 측정한 뒤 CAD 수치를 조정한다.

## 검증 상태

원본 제어 관절의 이름/순서/축/범위, 센서, 액추에이터 연결과 제한은 비교 검사했다. 추가 외장 질량과 관성은 몸체 관성에 합산했다. 외장 충돌 모델은 보수적인 바운딩 박스이며 구멍과 복잡한 오목 형상을 정확하게 표현하지 않는다.

원본과 Micro Rex 모두 기본 XML PD로 HOME 자세를 3초 유지하는 시험에서 넘어졌다. 이후 공식 ONNX와 BAM 모터 모델을 사용한 비교 시험을 추가했다. 추가된 46.53 g의 출력물 추정 질량과 관성을 포함한 현재 외장 모델의 결과는 [정책 호환 문서](POLICY_COMPATIBILITY.md)에 기록했다. 이 짧은 평지 시험은 실물 검증을 대체하지 않는다.

볼판 바깥면을 출력 베드에 놓는다. 안쪽 포켓은 1.2 mm 표면 두께를 남기고, 가장자리 3 mm 폭과 나사 주위는 원래 2 mm 두께를 유지한다. 이 보강 형상의 피로·충격·층간 강도는 아직 시험 전이다.

미검증: 실제 원본 제품과의 외장 간섭, 배선 경로, 전체 관절 가동 중 간섭, 카메라 전 시야각, 꼬리 고정 강도, 낙하/피로, 발열, 실제 재료 질량, 입 모터 동작, 보행 및 복구 정책.

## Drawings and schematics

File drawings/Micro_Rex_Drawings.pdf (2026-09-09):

# MICRO REX / ASSEMBLY REFERENCE

Microduck-compatible joint interface / independent T-rex retrofit / not factory manufacturing drawings

## PRINTED RETROFIT BOM

01 skull_cheek_left 7.7 g

02 teeth_left 0.4 g

03 brow_left 1.9 g

04 skull_cheek_right 7.7 g

05 teeth_right 0.4 g

06 brow_right 1.9 g

07 head_bridge_1 3.4 g

08 head_bridge_2 3.4 g

09 tail_segment_1 5.1 g

10 tail_segment_2 3.3 g

11 tail_segment_3 1.4 g

12 tail_saddle 3.4 g

13 forearm_left 1.5 g

14 arm_standoff_left 1.7 g

15 forearm_right 1.5 g

16 arm_standoff_right 1.7 g


Stock legs, motors, camera and head module are retained.
Cheek M2 bridge holes: diameter 2.4 mm; eye stem hole: diameter 5.4 mm. Eye: M2 x 6 plastic screw + OD8 x 0.5 washer, pilot diameter 1.6 x 6 deep. Head bridge strap slots: 4 x 2 mm; routing and retention need physical tests. Cheek: 1.2 mm face with 3 mm perimeter rib and full-thickness screw lands. Tail segment joints and decorative tooth retention remain unverified.
Arm brackets use M2 clearance and a 3 x 4 mm strap channel.
CAD coordinates use the source MJCF reference pose, not print-bed origin.
MICRO REX / Rev C / 2026-09-10 / mm / PROTOTYPE - verify fit before fabrication | 1 / 17

# SKULL CHEEK LEFT

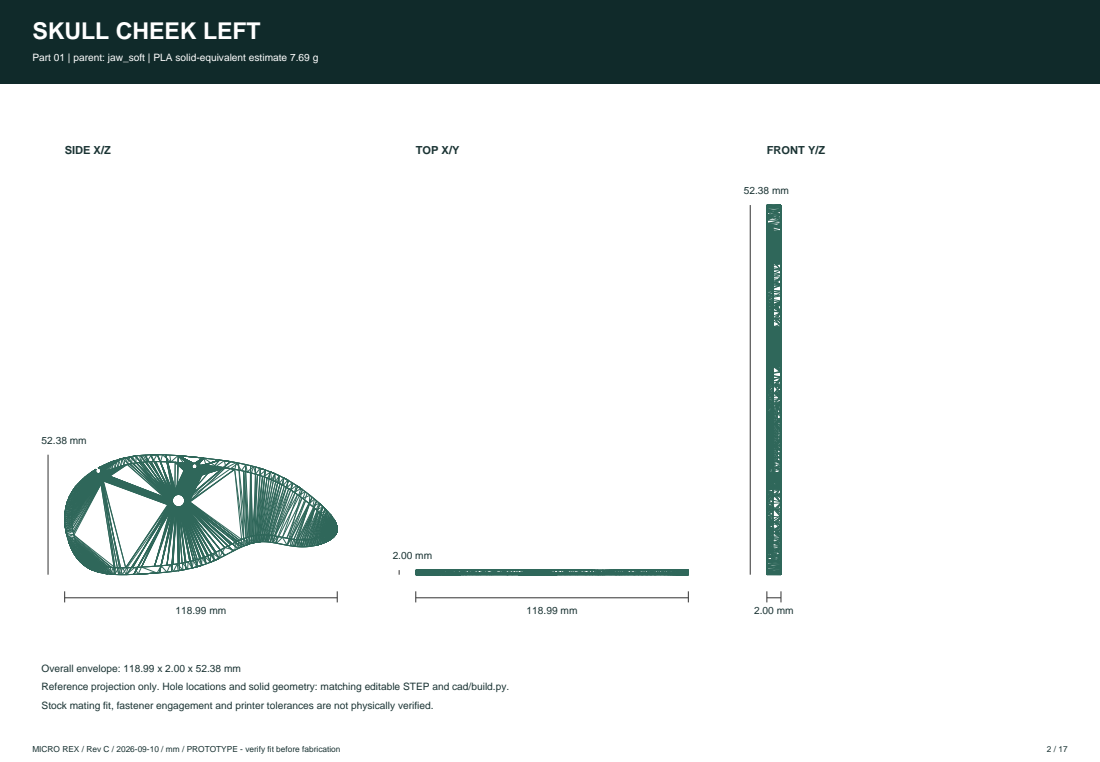
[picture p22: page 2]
SIDE X/Z; TOP X/Y; FRONT Y/Z; MICRO REX / Rev C / 2026-09-10 / mm / PROTOTYPE - verify fit before fabrication

Part 01 | parent: jaw_soft | PLA solid-equivalent estimate 7.69 g

Overall envelope: 118.99 x 2.00 x 52.38 mm
Reference projection only. Hole locations and solid geometry: matching editable STEP and cad/build.py.
Stock mating fit, fastener engagement and printer tolerances are not physically verified.

# TEETH LEFT

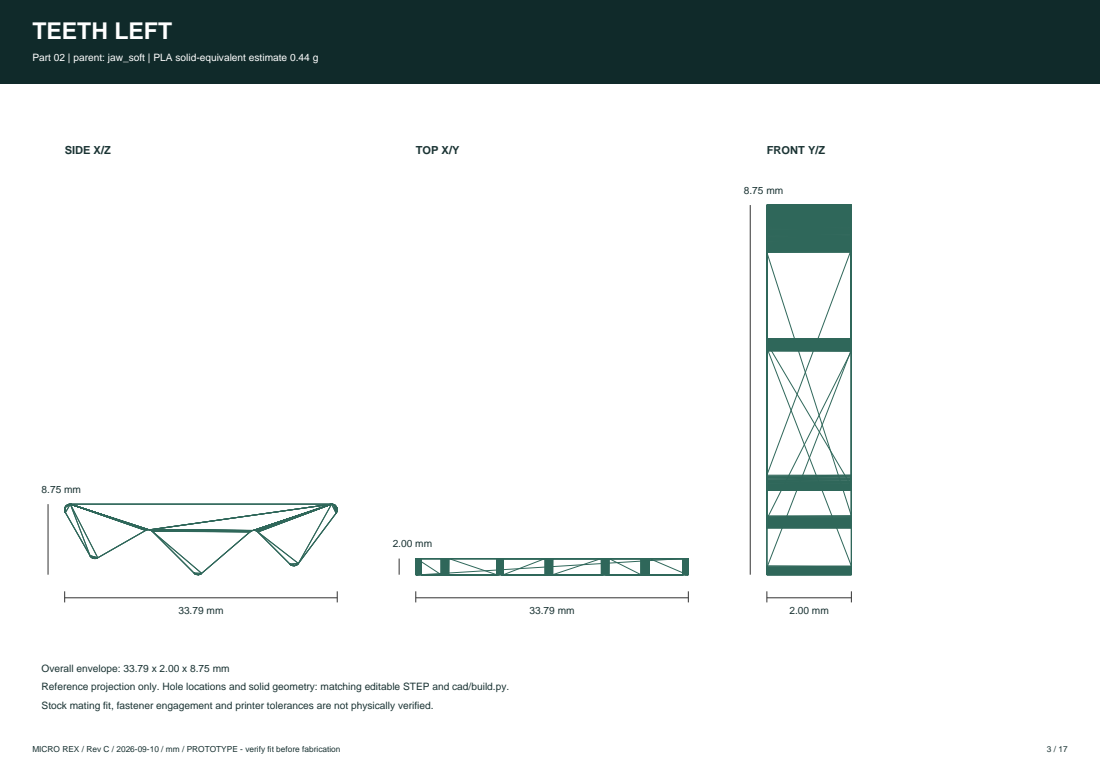
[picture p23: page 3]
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

Part 02 | parent: jaw_soft | PLA solid-equivalent estimate 0.44 g

Overall envelope: 33.79 x 2.00 x 8.75 mm
Reference projection only. Hole locations and solid geometry: matching editable STEP and cad/build.py.
Stock mating fit, fastener engagement and printer tolerances are not physically verified.

# BROW LEFT

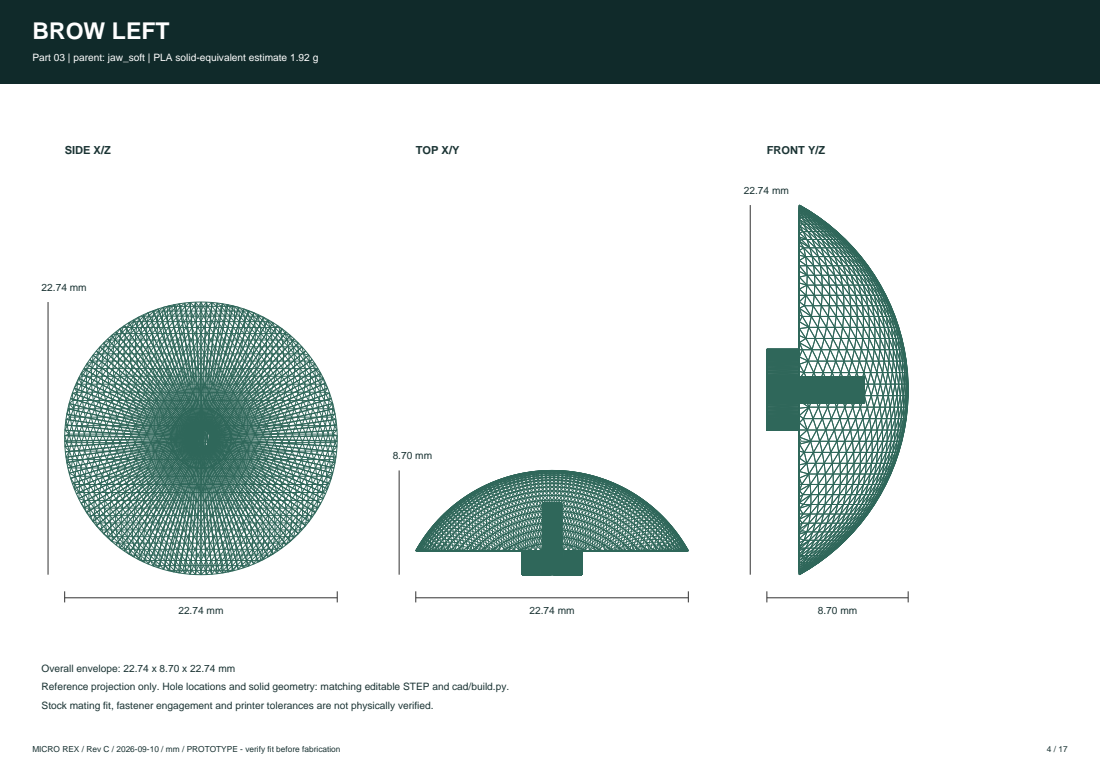
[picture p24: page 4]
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

Part 03 | parent: jaw_soft | PLA solid-equivalent estimate 1.92 g

Overall envelope: 22.74 x 8.70 x 22.74 mm
Reference projection only. Hole locations and solid geometry: matching editable STEP and cad/build.py.
Stock mating fit, fastener engagement and printer tolerances are not physically verified.

# SKULL CHEEK RIGHT

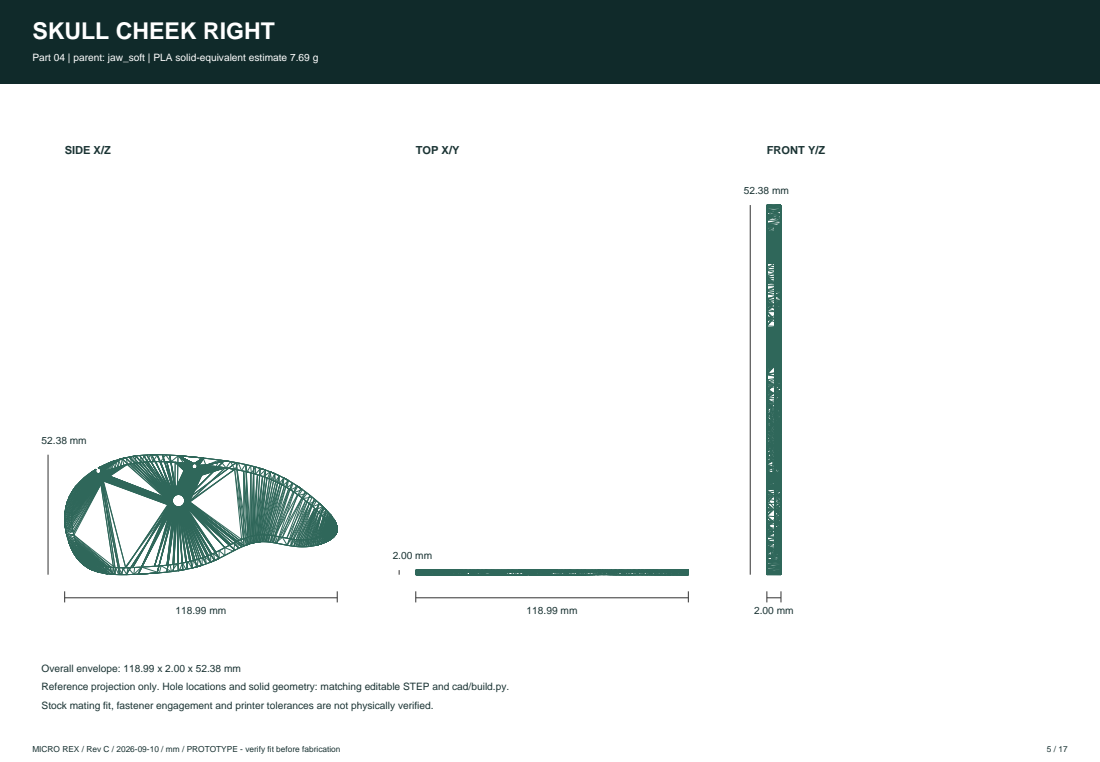
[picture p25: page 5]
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

Part 04 | parent: jaw_soft | PLA solid-equivalent estimate 7.69 g

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

# TEETH RIGHT

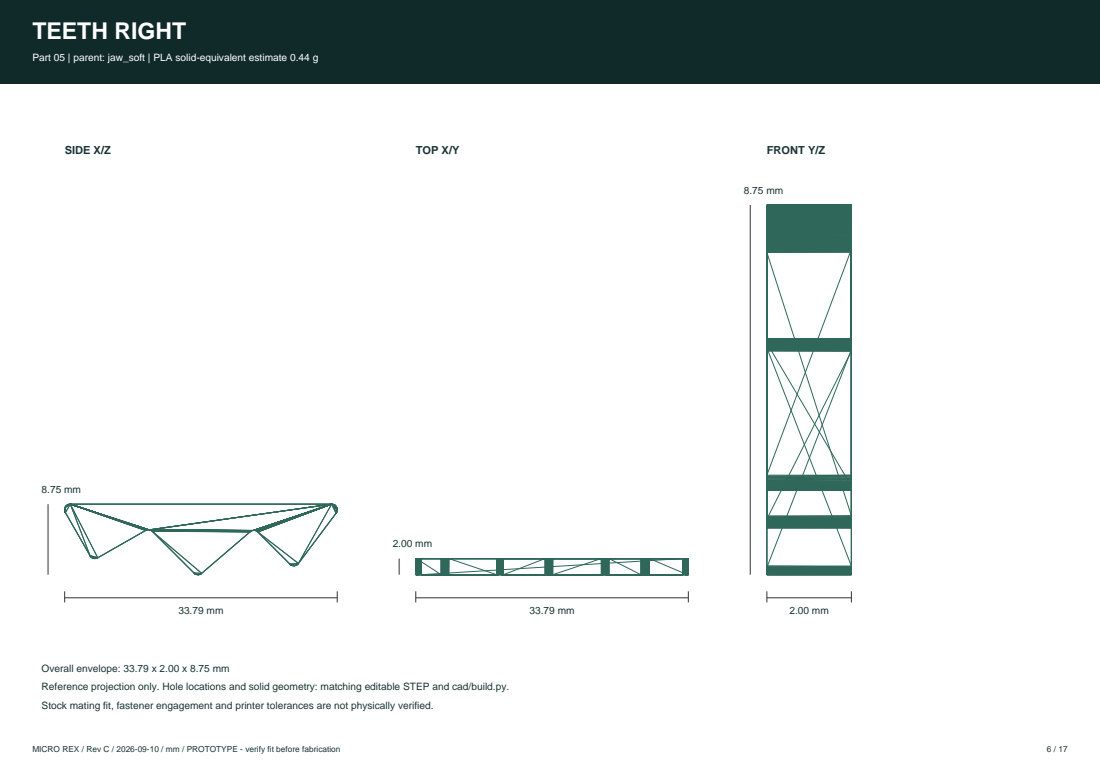
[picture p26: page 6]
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

Part 05 | parent: jaw_soft | PLA solid-equivalent estimate 0.44 g

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

# BROW RIGHT

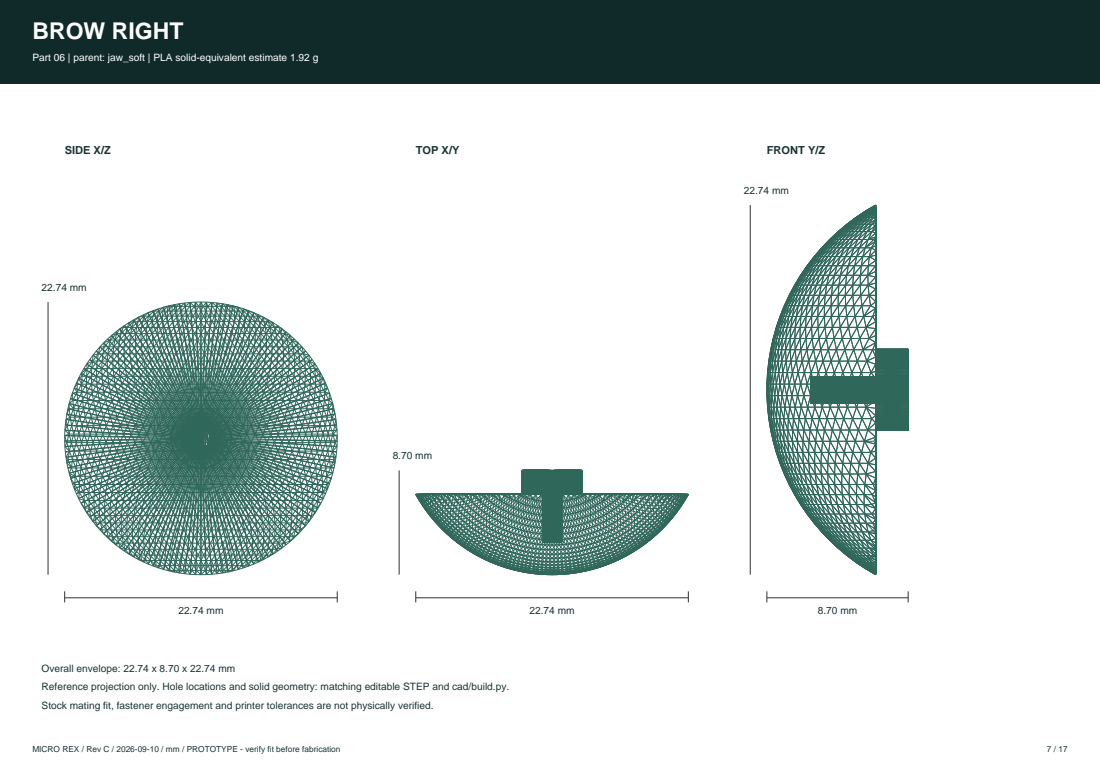
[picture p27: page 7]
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

Part 06 | parent: jaw_soft | PLA solid-equivalent estimate 1.92 g

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

# HEAD BRIDGE 1

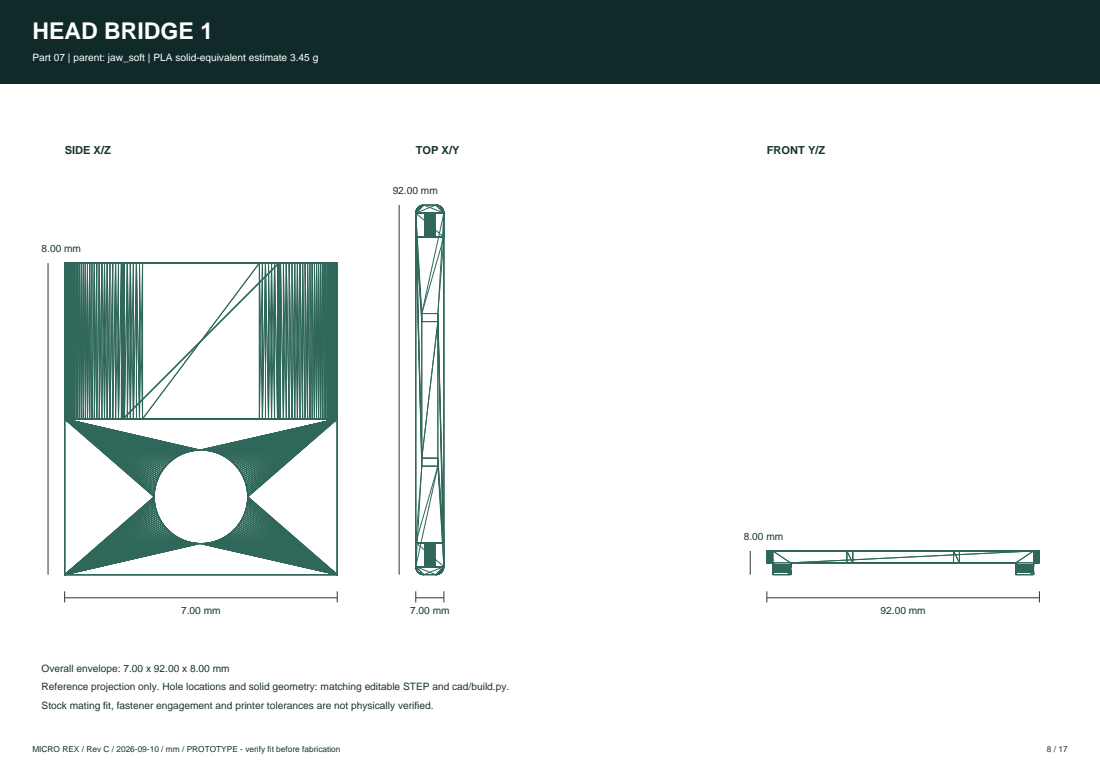
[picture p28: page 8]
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

Part 07 | parent: jaw_soft | PLA solid-equivalent estimate 3.45 g

Overall envelope: 7.00 x 92.00 x 8.00 mm
Reference projection only. Hole locations and solid geometry: matching editable STEP and cad/build.py.
Stock mating fit, fastener engagement and printer tolerances are not physically verified.
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

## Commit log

2026-09-07 Create Micro Rex T-rex retrofit CAD, drawings, viewer, and interface validation
    [arm_standoff_left.step, arm_standoff_left.stl, arm_standoff_left_local.stl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]
2026-09-07 Record checksums for released CAD and model artifacts
2026-09-07 Run numeric model validation without requiring a graphics driver
2026-09-09 Restore Microduck-based Rex design with official policy comparison and replay
    [arm_standoff_left.step, arm_standoff_right.step, brow_left.step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]
2026-09-09 Present cute same-joint Rex with lighter ribbed cheeks and verified design reports
    [arm_standoff_left.step, arm_standoff_left.stl, arm_standoff_left_local.stl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]
